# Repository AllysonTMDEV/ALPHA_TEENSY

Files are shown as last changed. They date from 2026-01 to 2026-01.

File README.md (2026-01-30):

# AFC - Alpha Flight Controller (Teensy 4.1)





## Visao Geral

Controlador de navegacao desenvolvido pela **Alpha Subsea** para ROVs e drones subaquaticos, baseado na plataforma **Teensy 4.1** (ARM Cortex-M7 @ 600MHz).

### Caracteristicas Principais:
- **MCU:** Teensy 4.1 (600MHz, 1MB RAM)
- **Sensores:** IMU (ICM-42688-P), Magnetometro (LIS3MDL), Barometro (BMP390), Profundidade (MS5837-30BA)
- **PWM:** 16 canais via PCA9685 (8 thrusters + 4 servos)
- **Comunicacao:** Serial 1Mbps com Raspberry Pi
- **ADC:** ADS1115 16-bit para monitoramento de tensao/corrente

## Estrutura de Arquivos

```
AFC_CICLO DESENVOLVIMENTO.html    # Ciclo de desenvolvimento (40% completo)
AFC_TEENSY_PCB_DOCUMENTACAO.md    # Documentacao tecnica completa
BOM_AFC_TEENSY_LCSC.csv           # Lista de materiais com codigos LCSC
Gerber_*.zip                       # Arquivos Gerber para fabricacao
PCB_*.json                         # PCB EasyEDA
PCB_*.kicad_pcb                    # PCB KiCad
SCH_*.json                         # Esquematico EasyEDA
Schematic_*.pdf                    # Esquematico PDF
Sheet_1_*.schdoc                   # Esquematico Altium (para KiCad)
*.png                              # Screenshots de validacao
```

## Status do Projeto

| Fase | Progresso | Status |
|---|---|---|
| 1. Plan | 100% | Concluido |
| 2. Code | 100% | Firmware + Esquematico prontos |
| 3. Build | 100% | Gerbers prontos para fabricacao |
| 4. Test | 0% | Pendente |
| 5. Homologation | 0% | Pendente |

**Progresso Geral: 42%**

## BOM - Lista de Materiais

Total de **63 componentes** com codigos LCSC para montagem SMD.

### Componentes Principais:
| Componente | Modelo | LCSC |
|---|---|---|
| IMU 6-DoF | ICM-42688-P | C1850418 |
| Magnetometro | LIS3MDL | C478483 |
| Barometro | BMP390 | C9900016584 |
| PWM Driver | PCA9685PW | C2678753 |
| ADC 16-bit | ADS1115 | C37593 |
| Buck Converter | MP1584EN | C15051 |
| Power Monitor | INA226 | C49851 |

**Custo estimado:** ~$50-70 USD (sem Teensy e MS5837)

## Como Fabricar

1. **Fabricacao da PCB:**
   - Utilizar o arquivo `Gerber_*.zip` para fabricacao
   - BOM disponivel em `BOM_AFC_TEENSY_LCSC.csv`

2. **Importar no KiCad 9.0:**
   - `File` -> `Import Project...` -> `Altium Designer`
   - Selecionar `Sheet_1_*.schdoc`

## Firmware

Firmware desenvolvido em PlatformIO com as seguintes features:
- Loop de controle a 400Hz
- PID com anti-windup
- Mixer para 8 thrusters (BlueROV2 Heavy)
- Protocolo binario com CRC16
- Telemetria a 50Hz

## Documentacao

- [Documentacao Tecnica](AFC_TEENSY_PCB_DOCUMENTACAO.md)
- [Ciclo de Desenvolvimento](AFC_CICLO%20DESENVOLVIMENTO.html)
- [BOM LCSC](BOM_AFC_TEENSY_LCSC.csv)

## Equipe

**Alpha Subsea** - Tecnologia Submarina  
Desenvolvido por **Arbor Gestao**

---

*Ultima atualizacao: Janeiro 2026*

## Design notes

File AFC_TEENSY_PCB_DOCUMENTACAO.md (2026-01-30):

# DOCUMENTACAO TECNICA - AFC TEENSY PCB
## Placa de Controle para ROV (Remotely Operated Vehicle)

---

## 1. INFORMACOES GERAIS DO PROJETO

| Parametro | Valor |
|---|---|
| Nome do Projeto | AFC Teensy Controller |
| Versao | 1.0 |
| Data de Criacao | Janeiro 2026 |
| Plataforma de Design | EasyEDA |
| Fabricante Alvo | JLCPCB |

---

## 2. ESPECIFICACOES DA PCB

| Parametro | Valor |
|---|---|
| Dimensoes | 100mm x 80mm |
| Camadas de Cobre | 2 (Top e Bottom) |
| Formato | Retangular |
| Unidade de Medida | Milimetros (mm) |
| Espessura da Placa | 1.6mm (padrao) |
| Material | FR-4 |

---

## 3. LISTA COMPLETA DE COMPONENTES E FOOTPRINTS

### 3.1 Microcontrolador

| Designador | Componente | Descricao | Footprint |
|---|---|---|---|
| U1 | Teensy 4.1 | Microcontrolador principal ARM Cortex-M7 | Modulo Teensy 4.1 |

### 3.2 Sensores I2C

| Designador | Componente | Descricao | Footprint | Endereco I2C |
|---|---|---|---|---|
| U2 | INA226 | Monitor de corrente/tensao | MSOP-10 | 0x40 |
| U3 | ICM-42688-P | IMU 6-DOF (Acelerometro + Giroscopio) | QFN-14 | 0x68 |
| U4 | LIS3MDL | Magnetometro 3 eixos | LGA-12 | 0x1C |
| U5 | BMP390 | Barometro/Altimetro | LGA-10 | 0x76 |
| U6 | ADS1115 | ADC 16-bit 4 canais | MSOP-10 | 0x48 |

### 3.3 Reguladores de Tensao

| Designador | Componente | Descricao | Entrada | Saida | Footprint |
|---|---|---|---|---|---|
| U7 | MP1584EN | Regulador DC-DC Step-Down | 12V | 5V | SOIC-8 |
| U8 | AMS1117-3.3 | Regulador LDO | 5V | 3.3V | SOT-223 |
| U12 | MP1584EN | Regulador DC-DC Step-Down (secundario) | 12V | 5V | SOIC-8 |

### 3.4 Circuitos de Protecao e Monitoramento

| Designador | Componente | Descricao | Footprint |
|---|---|---|---|
| U10 | Voltage Monitor | Monitor de tensao | SOT-23 |
| U11 | Crystal 32.768kHz | Cristal oscilador | HC-49S |
| D1 | SMBJ24A-TR | TVS Diode protecao ESD | SMB |
| D2 | SS34 | Diodo Schottky | SMA |
| D3 | SS34 | Diodo Schottky | SMA |

### 3.5 Conectores de Servo/PWM (3 pinos) - ATUALIZADOS

| Designador | Funcao | Footprint Original | Footprint Atualizado | LCSC Code |
|---|---|---|---|---|
| U13 (RX/TX11) | Servo Output 11 | SM03B-GHS-TB | CONN-TH_3P-P2.50_B3B-XH-A-BK-LF-SN | C144394 |
| U14 (RX/TX10) | Servo Output 10 | SM03B-GHS-TB | CONN-TH_3P-P2.50_B3B-XH-A-BK-LF-SN | C144394 |
| U15 (RX/TX9) | Servo Output 9 | SM03B-GHS-TB | CONN-TH_3P-P2.50_B3B-XH-A-BK-LF-SN | C144394 |
| U16 (RX/TX8) | Servo Output 8 | SM03B-GHS-TB | CONN-TH_3P-P2.50_B3B-XH-A-BK-LF-SN | C144394 |
| U17 (RX/TX7) | Servo Output 7 | SM03B-GHS-TB | CONN-TH_3P-P2.50_B3B-XH-A-BK-LF-SN | C144394 |
| U18 (RX/TX6) | Servo Output 6 | SM03B-GHS-TB | CONN-TH_3P-P2.50_B3B-XH-A-BK-LF-SN | C144394 |
| U19 (RX/TX5) | Servo Output 5 | SM03B-GHS-TB | CONN-TH_3P-P2.50_B3B-XH-A-BK-LF-SN | C144394 |
| U20 (RX/TX4) | Servo Output 4 | SM03B-GHS-TB | CONN-TH_3P-P2.50_B3B-XH-A-BK-LF-SN | C144394 |
| U21 (RX/TX3) | Servo Output 3 | SM03B-GHS-TB | CONN-TH_3P-P2.50_B3B-XH-A-BK-LF-SN | C144394 |
| U22 (RX/TX2) | Servo Output 2 | SM03B-GHS-TB | CONN-TH_3P-P2.50_B3B-XH-A-BK-LF-SN | C144394 |
| U23 (RX/TX1) | Servo Output 1 | SM03B-GHS-TB | CONN-TH_3P-P2.50_B3B-XH-A-BK-LF-SN | C144394 |

Pinagem dos conectores de servo (B3B-XH-A):
- Pino 1: GND
- Pino 2: VCC (5V)
- Pino 3: Sinal PWM

### 3.6 Conectores I2C (4 pinos) - ATUALIZADOS

| Designador | Funcao | Footprint Original | Footprint Atualizado | LCSC Code |
|---|---|---|---|---|
| P1 | I2C Port 1 | JST-4PIN | CONN-TH_B4B-XH-A-LF-SN | C144395 |
| P2 | I2C Port 2 | JST-4PIN | CONN-TH_B4B-XH-A-LF-SN | C144395 |
| P3 | I2C Port 3 | JST-4PIN | CONN-TH_B4B-XH-A-LF-SN | C144395 |
| P4 | I2C Port 4 | JST-4PIN | CONN-TH_B4B-XH-A-LF-SN | C144395 |
| P5 | I2C Port 5 | JST-4PIN | CONN-TH_B4B-XH-A-LF-SN | C144395 |
| P6 | I2C Port 6 | JST-4PIN | CONN-TH_B4B-XH-A-LF-SN | C144395 |
| P7 | I2C Port 7 | JST-4PIN | CONN-TH_B4B-XH-A-LF-SN | C144395 |
| P8 | I2C Port 8 | JST-4PIN | CONN-TH_B4B-XH-A-LF-SN | C144395 |

Pinagem dos conectores I2C (B4B-XH-A):
- Pino 1: GND
- Pino 2: VCC (3.3V)
- Pino 3: SDA
- Pino 4: SCL

### 3.7 Outros Conectores

| Designador | Componente | Descricao | Footprint |
|---|---|---|---|
| CN1 | Conector de Entrada | Entrada de alimentacao principal 12V | Conector Screw Terminal |
| P9 | Header 2x5 | Conector de expansao | PHD2.0mm-2X5 |

### 3.8 Componentes de Interface

| Designador | Componente | Descricao | Footprint |
|---|---|---|---|
| SW1 | Tactile Switch | Botao ARM | 6x6mm Tactile |
| SW2 | Tactile Switch | Botao Emergency Stop | 6x6mm Tactile |
| LED1 | WS2812B-5050 | LED RGB Status 1 | LED-SMD_5050 |
| LED2 | WS2812B-5050 | LED RGB Status 2 | LED-SMD_5050 |
| BUZZER1 | Buzzer 2700Hz | Buzzer piezoeletrico | BUZ-SMD_4P-L8.5 |

### 3.9 Transistores/MOSFETs

| Designador | Componente | Descricao | Footprint |
|---|---|---|---|
| Q1 | AO3400A | N-Channel MOSFET | SOT-23-3 |
| Q2 | AO3400A | N-Channel MOSFET | SOT-23-3 |

### 3.10 Resistores

| Designador | Valor | Descricao | Footprint |
|---|---|---|---|
| R1 | 10K | Pull-up/Pull-down | 0402 |
| R2 | 10K | Pull-up/Pull-down | 0402 |
| R3 | 10K | Pull-up/Pull-down | 0402 |
| R4 | 10K | Pull-up/Pull-down | 0402 |
| R5 | 10K | Pull-up/Pull-down | 0402 |
| R6 | 10K | Pull-up/Pull-down | 0402 |
| R7 | 10K | Pull-up/Pull-down | 0402 |
| R8 | 10K | Pull-up/Pull-down | 0402 |
| R9 | 4.7K | Pull-up I2C SDA | 0402 |
| R10 | 4.7K | Pull-up I2C SCL | 0402 |
| R11 | 1K | Resistor LED | 0402 |
| R12 | 1K | Resistor LED | 0402 |
| R13 | 100R | Resistor de protecao | 0402 |
| R14 | 100R | Resistor de protecao | 0402 |
| R15 | 100R | Resistor de protecao | 0402 |
| R16 | 100R | Resistor de protecao | 0402 |
| R17 | 0.1R | Resistor shunt para INA226 | 2512 |

### 3.11 Capacitores

| Designador | Valor | Descricao | Footprint |
|---|---|---|---|
| C1 | 10uF | Capacitor de desacoplamento | 0805 |
| C2 | 10uF | Capacitor de desacoplamento | 0805 |
| C3 | 10uF | Capacitor de desacoplamento | 0805 |
| C4 | 10uF | Capacitor de desacoplamento | 0805 |
| C5 | 100nF | Capacitor de bypass | 0402 |
| C6 | 100nF | Capacitor de bypass | 0402 |
| C7 | 100nF | Capacitor de bypass | 0402 |
| C8 | 100nF | Capacitor de bypass | 0402 |
| C9 | 100nF | Capacitor de bypass | 0402 |
| C10 | 100nF | Capacitor de bypass | 0402 |
| C11 | 100nF | Capacitor de bypass | 0402 |
| C12 | 100nF | Capacitor de bypass | 0402 |
| C13 | 100nF | Capacitor de bypass | 0402 |
| C14 | 100nF | Capacitor de bypass | 0402 |
| C15 | 100nF | Capacitor de bypass | 0402 |
| C16 | 1uF | Capacitor de filtragem | 0402 |
| C17 | 22uF | Capacitor regulador entrada | 0805 |
| C18 | 22uF | Capacitor regulador saida | 0805 |
| C19 | 47uF | Capacitor bulk entrada | 1206 |
| C20 | 47uF | Capacitor bulk saida | 1206 |

---

## 4. HISTORICO DE ALTERACOES

### 4.1 Alteracoes de Footprint

| Data | Componentes | Alteracao | Motivo |
|---|---|---|---|
| Jan 2026 | U13-U23 (RX/TX1-11) | SM03B-GHS-TB para B3B-XH-A | Orientacao vertical para facilitar conexao de cabos pela parte superior |
| Jan 2026 | P1-P8 | JST-4PIN generico para B4B-XH-A | Footprint com modelo 3D e compativel com JLCPCB |

### 4.2 Alteracoes de Nomenclatura

| Componente Original | Novo Nome | Motivo |
|---|---|---|
| RX/TX1 | U23 | Padronizacao de nomenclatura |
| RX/TX2 | U22 | Padronizacao de nomenclatura |
| RX/TX3 | U21 | Padronizacao de nomenclatura |
| RX/TX4 | U20 | Padronizacao de nomenclatura |
| RX/TX5 | U19 | Padronizacao de nomenclatura |
| RX/TX6 | U18 | Padronizacao de nomenclatura |
| RX/TX7 | U17 | Padronizacao de nomenclatura |
| RX/TX8 | U16 | Padronizacao de nomenclatura |
| RX/TX9 | U15 | Padronizacao de nomenclatura |
| RX/TX10 | U14 | Padronizacao de nomenclatura |
| RX/TX11 | U13 | Padronizacao de nomenclatura |

---

## 5. LAYOUT DA PCB

### 5.1 Distribuicao de Areas

| Area | Localizacao | Componentes |
|---|---|---|
| Entrada de Energia | Borda esquerda superior | CN1, D1, U10 |
| Reguladores | Topo central-esquerdo | U7, U8, U12, C17-C20 |
| Microcontrolador | Centro-esquerda | U1 (Teensy) |
| Sensores I2C | Centro-esquerda | U2, U3, U4, U5, U6, U11 |
| Interface Usuario | Topo central | SW1, SW2, LED1, LED2, BUZZER1 |
| Conectores PWM | Centro | RX/TX1-11 (U13-U23) em grade 4x3 |
| Conectores I2C | Inferior central | P1-P8 em grade 4x2 |
| Conector Expansao | Borda direita | P9 |
| MOSFETs | Direita superior | Q1, Q2 |
| Resistores | Borda direita | R1-R17 |
| Capacitores | Borda inferior | C1-C16 |

### 5.2 Furos de Montagem

| Posicao | Coordenadas Aproximadas |
|---|---|
| Canto superior esquerdo | (5mm, 5mm) |
| Canto superior direito | (95mm, 5mm) |
| Canto inferior esquerdo | (5mm, 75mm) |
| Canto inferior direito | (95mm, 75mm) |

---

## 6. REDES DE ALIMENTACAO

### 6.1 Tensoes do Sistema

| Rede | Tensao | Fonte | Consumidores |
|---|---|---|---|
| VIN | 12V | Entrada externa | Reguladores |
| 5V | 5V | U7 (MP1584EN) | Servos, Teensy |
| 3V3 | 3.3V | U8 (AMS1117) | Sensores I2C, LEDs |
| GND | 0V | Referencia comum | Todos os componentes |

### 6.2 Barramentos

| Barramento | Sinais | Componentes Conectados |
|---|---|---|
| I2C | SDA, SCL | U2, U3, U4, U5, U6, P1-P8 |
| PWM | PWM1-PWM11 | U13-U23 |
| SPI | MOSI, MISO, SCK, CS | Reservado |

---

## 7. CONSIDERACOES DE DESIGN

### 7.1 Orientacao dos Conectores

Todos os conectores de servo (U13-U23) e I2C (P1-P8) foram posicionados com a abertura voltada para CIMA, permitindo:
- Conexao de cabos pela parte superior da placa
- Facilidade de manutencao
- Acesso visual aos conectores durante operacao

### 7.2 Posicionamento de Componentes Criticos

- Capacitores de desacoplamento proximos aos pinos de alimentacao dos ICs
- Resistor shunt (R17) proximo ao INA226 (U2)
- Cristal (U11) proximo ao microcontrolador
- Reguladores afastados dos sensores para minimizar interferencia termica

### 7.3 Recomendacoes para Roteamento

- Trilhas de alimentacao: minimo 0.5mm de largura
- Trilhas de sinal: 0.25mm de largura
- Via termica sob reguladores
- Plano de terra continuo na camada inferior
- Evitar trilhas longas para sinais I2C

---

## 8. LISTA DE MATERIAIS (BOM) - CODIGOS LCSC ATUALIZADOS

### 8.1 ICs Principais

| Ref | LCSC | Componente | Footprint | Tipo |
|-----|---|---|---|---|
| U1 | C2678753 | PCA9685PW,118 (PWM Driver 16ch) | TSSOP-28 | Extended |
| U2 | C37593 | ADS1115IDGSR (ADC 16-bit) | MSOP-10 | Extended |
| U3 | C1850418 | ICM-42688-P (IMU 6-axis) | LGA-14 | Extended |
| U4 | C478483 | LIS3MDLTR (Magnetometro) | LGA-12 | Extended |
| U5 | C9900016584 | BMP390 (Barometro) | LGA-10 | Extended |
| U6 | C49851 | INA226AIDGSR (Power Monitor) | MSOP-10 | Extended |
| U7 | C15051 | MP1584EN-LF-Z (Buck 3A) | SOIC-8 EP | Extended |
| U8 | C6186 | AMS1117-3.3 (LDO 3.3V) | SOT-223 | Basic |
| U10 | C9900007450 | PPTC 1.5A/13.2V (Fusivel) | 1206 | Extended |
| U11 | C17701336 | Crystal 24MHz | SMD 3225 | Extended |

### 8.2 Diodos e Transistores

| Ref | LCSC | Componente | Footprint | Tipo |
|-----|---|---|---|---|
| D1 | C133668 | SMBJ24A-TR (TVS 24V) | SMB | Extended |
| D2 | C8678 | SS34 (Schottky 3A 40V) | SMA | Basic |
| D3 | C8678 | SS34 (Schottky 3A 40V) | SMA | Basic |
| Q1 | C20917 | AO3400A (MOSFET N-CH) | SOT-23 | Basic |
| Q2 | C20917 | AO3400A (MOSFET N-CH) | SOT-23 | Basic |

### 8.3 Resistores

| Ref | LCSC | Valor | Footprint | Tipo |
|-----|---|---|---|---|
| R1-R8 | C25744 | 10kΩ | 0402 | Basic |
| R9-R12 | C25900 | 4.7kΩ | 0402 | Basic |
| R13-R16 | C2889360 | 330Ω | 0402 | Extended |
| R17 | C76272 | 0.01Ω 1W Shunt | 2512 | Extended |

### 8.4 Capacitores

| Ref | LCSC | Valor | Footprint | Tipo |
|-----|---|---|---|---|
| C1-C4 | C15850 | 10uF 25V | 0805 | Basic |
| C5-C12 | C1525 | 100nF 50V | 0402 | Basic |
| C13-C16 | C52923 | 1uF 16V | 0402 | Basic |
| C17-C18 | C45783 | 22uF 25V | 0805 | Basic |
| C19-C20 | C5448950 | 47uF 10V | 1206 | Extended |

### 8.5 LEDs, Buzzer e Conectores

| Ref | LCSC | Componente | Footprint | Tipo |
|-----|---|---|---|---|
| LED1-LED2 | C2838584 | WS2812B-5050RGB | 5050 | Extended |
| BUZZER1 | C94599 | MLT-8530 (2700Hz) | SMD 8.5x8.5 | Extended |
| CN1 | C5306499 | S4B-XH-SM4-TB(LF)(SN) | JST XH 4P | Extended |
| P9 | C49123 | PHD2.0mm-2X5 Header | THT 2x5 | Extended |

### 8.6 Resumo de Quantidades

| Categoria | Quantidade |
|---|---|
| ICs | 11 |
| Diodos | 3 |
| Transistores | 2 |
| Resistores | 17 |
| Capacitores | 20 |
| LEDs | 2 |
| Buzzer | 1 |
| Conectores | 2 |
| **TOTAL SMT** | **58** |
| Teensy 4.1 (separado) | 1 |

### 8.7 Estimativa de Custos (USD)

| Item | Valor |
|---|---|
| Basic Parts (35 unid) | ~$1.50 |
| Extended Parts (28 unid) | ~$25-30 |
| Taxa Extended (17 tipos x $3) | ~$51 |
| PCB (5 unidades) | ~$5-10 |
| Teensy 4.1 | ~$30 |
| **TOTAL** | **~$115-125** |

---

## 9. PROXIMOS PASSOS

| Etapa | Status | Descricao |
|---|---|---|
| 1. Esquematico | COMPLETO | Diagrama multifilar finalizado |
| 2. Conversao para PCB | COMPLETO | Importacao de componentes |
| 3. Atualizacao de Footprints | COMPLETO | U13-U23 e P1-P8 atualizados |
| 4. Posicionamento | COMPLETO | Layout conforme guia visual |
| 5. Auto-Router | COMPLETO | Roteamento das trilhas |
| 6. Planos de Cobre | COMPLETO | GND e VCC planes |
| 7. DRC | COMPLETO | 0 erros |
| 8. Gerber | COMPLETO | Arquivos gerados |
| 9. BOM LCSC | COMPLETO | Lista atualizada com codigos |

---

## 10. ARQUIVOS DO PROJETO

| Arquivo | Descricao |
|---|---|
| SCH_PROJETO-AFC-(LAYOUT-ATUALIZADO-002)_2026-01-30.json | Esquematico EasyEDA |
| Schematic_PROJETO-AFC-(LAYOUT-ATUALIZADO-002)_2026-01-30.pdf | Esquematico PDF |
| PCB_PCB_PROJETO-AFC-(LAYOUT-ATUALIZADO-002)_2_2026-01-30.json | PCB EasyEDA |
| PCB_PCB_PROJETO-AFC-(LAYOUT-ATUALIZADO-002)_2_2026-01-30.kicad_pcb | PCB KiCad |
| PCB_PCB_PROJETO-AFC-(LAYOUT-ATUALIZADO-002)_2_2026-01-30.pdf | PCB PDF |
| Gerber_PROJETO-AFC-...2026-01-30.zip | Arquivos Gerber para JLCPCB |
| BOM_AFC_TEENSY_LCSC.csv | Lista de materiais com codigos LCSC |
| AFC_TEENSY_PCB_DOCUMENTACAO.md | Esta documentacao |
| PLACA AFC FINAL 0 ERROS.png | Screenshot DRC aprovado |

---

## 11. INFORMACOES DE CONTATO E REVISAO

| Campo | Valor |
|---|---|
| Projetista | [Nome do Projetista] |
| Revisao | 1.0 |
| Data da Documentacao | Janeiro 2026 |
| Ultima Atualizacao | 30/01/2026 |

---

## NOTAS ADICIONAIS

1. Os footprints B3B-XH-A e B4B-XH-A sao conectores JST XH series, amplamente disponiveis e compativeis com JLCPCB SMT assembly.

2. Os conectores foram especificamente escolhidos para ter orientacao vertical, facilitando a conexao de cabos externos.

3. O layout foi inspirado na placa Navigator da BlueRobotics, otimizado para aplicacoes de ROV.

4. Todos os componentes possuem codigos LCSC validos para fabricacao via JLCPCB.

---

FIM DO DOCUMENTO

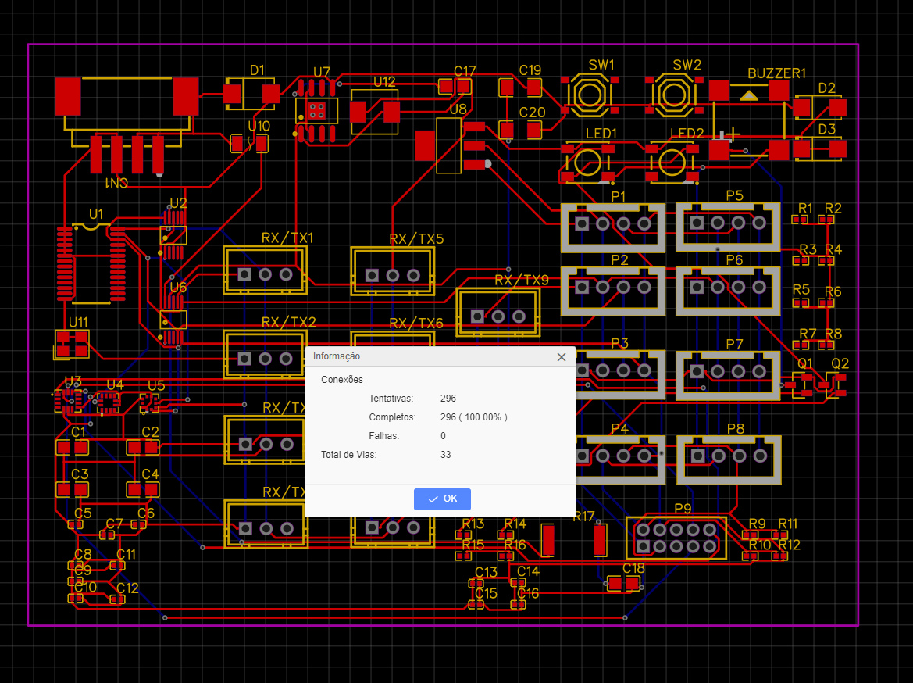
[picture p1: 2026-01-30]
PLACA AFC FINAL 0 ERROS.png

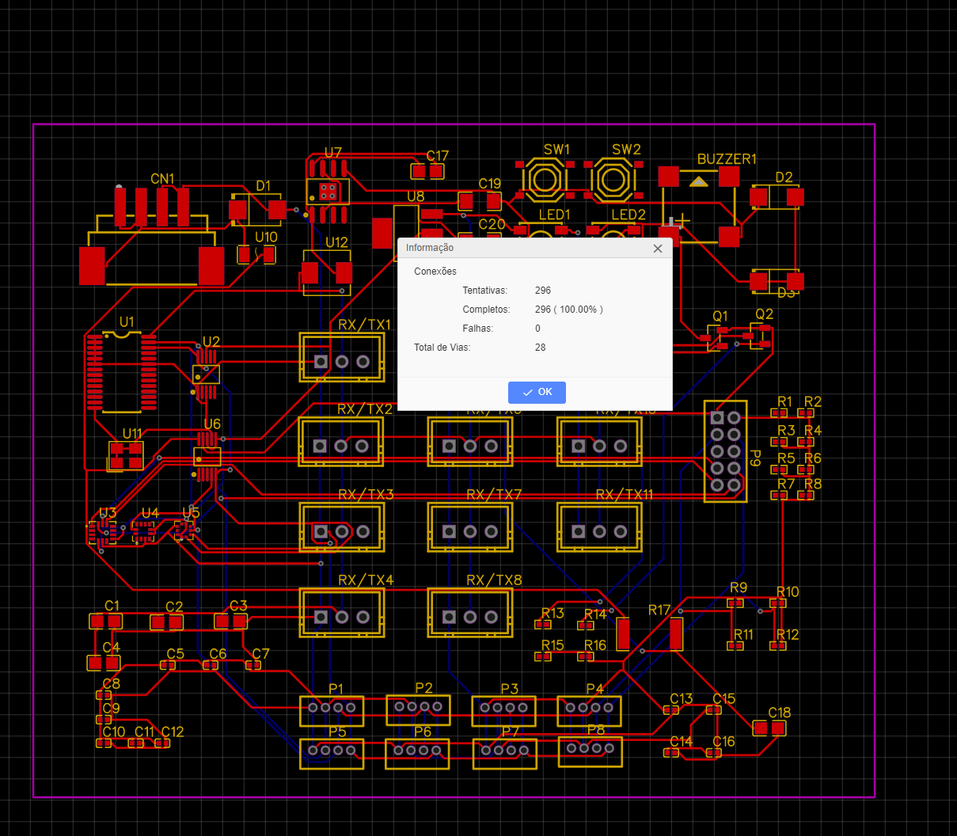
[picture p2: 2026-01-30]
RETRABALHO FOOTPRINT ZERO ERROS TEENSY.png

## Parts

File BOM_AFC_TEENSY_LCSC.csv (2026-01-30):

Referencia | Quantidade | Valor/Part Number | Descricao | Footprint | LCSC | Tipo JLCPCB
========== ICs PRINCIPAIS ==========
U1 | 1 | PCA9685PW 118 | PWM Driver 16ch I2C | TSSOP-28 | C2678753 | Extended Part
U2 | 1 | ADS1115IDGSR | ADC 16-bit 4ch I2C | MSOP-10 | C37593 | Extended Part
U3 | 1 | ICM-42688-P | IMU 6-axis Accel/Gyro | LGA-14 | C1850418 | Extended Part
U4 | 1 | LIS3MDLTR | Magnetometro 3-axis I2C | LGA-12 | C478483 | Extended Part
U5 | 1 | BMP390 | Barometro/Altimetro I2C | LGA-10 | C9900016584 | Extended Part
U6 | 1 | INA226AIDGSR | Monitor Corrente/Tensao I2C | MSOP-10 | C49851 | Extended Part
U7 | 1 | MP1584EN-LF-Z | Buck Converter 3A | SOIC-8 EP | C15051 | Extended Part
U8 | 1 | AMS1117-3.3 | LDO Regulador 3.3V 1A | SOT-223 | C6186 | Basic Part
U10 | 1 | PPTC 1.5A/13.2V | Fusivel Resetavel | 1206 | C9900007450 | Extended Part
U11 | 1 | 7325-2400A1210-03 | Crystal 24MHz | SMD 3225 | C17701336 | Extended Part
========== DIODOS ==========
D1 | 1 | SMBJ24A-TR | TVS Diodo 24V | SMB | C133668 | Extended Part
D2 | 1 | SS34 | Schottky Diodo 3A 40V | SMA | C8678 | Basic Part
D3 | 1 | SS34 | Schottky Diodo 3A 40V | SMA | C8678 | Basic Part
========== TRANSISTORES ==========
Q1 | 1 | AO3400A | MOSFET N-CH 30V 5.7A | SOT-23 | C20917 | Basic Part
Q2 | 1 | AO3400A | MOSFET N-CH 30V 5.7A | SOT-23 | C20917 | Basic Part
========== RESISTORES ==========
R1 | 1 | 10kΩ | Resistor SMD | 0402 | C25744 | Basic Part
R2 | 1 | 10kΩ | Resistor SMD | 0402 | C25744 | Basic Part
R3 | 1 | 10kΩ | Resistor SMD | 0402 | C25744 | Basic Part
R4 | 1 | 10kΩ | Resistor SMD | 0402 | C25744 | Basic Part
R5 | 1 | 10kΩ | Resistor SMD | 0402 | C25744 | Basic Part
R6 | 1 | 10kΩ | Resistor SMD | 0402 | C25744 | Basic Part
R7 | 1 | 10kΩ | Resistor SMD | 0402 | C25744 | Basic Part
R8 | 1 | 10kΩ | Resistor SMD | 0402 | C25744 | Basic Part
R9 | 1 | 4.7kΩ | Resistor SMD | 0402 | C25900 | Basic Part
R10 | 1 | 4.7kΩ | Resistor SMD | 0402 | C25900 | Basic Part
R11 | 1 | 4.7kΩ | Resistor SMD | 0402 | C25900 | Basic Part
R12 | 1 | 4.7kΩ | Resistor SMD | 0402 | C25900 | Basic Part
R13 | 1 | 330Ω | Resistor SMD | 0402 | C2889360 | Extended Part
R14 | 1 | 330Ω | Resistor SMD | 0402 | C2889360 | Extended Part
R15 | 1 | 330Ω | Resistor SMD | 0402 | C2889360 | Extended Part
R16 | 1 | 330Ω | Resistor SMD | 0402 | C2889360 | Extended Part
R17 | 1 | 0.01Ω 1W | Resistor Shunt Sense | 2512 | C76272 | Extended Part
========== CAPACITORES ==========
C1 | 1 | 10uF 25V | Capacitor Ceramico | 0805 | C15850 | Basic Part
C2 | 1 | 10uF 25V | Capacitor Ceramico | 0805 | C15850 | Basic Part
C3 | 1 | 10uF 25V | Capacitor Ceramico | 0805 | C15850 | Basic Part
C4 | 1 | 10uF 25V | Capacitor Ceramico | 0805 | C15850 | Basic Part
C5 | 1 | 100nF 50V | Capacitor Ceramico | 0402 | C1525 | Basic Part
C6 | 1 | 100nF 50V | Capacitor Ceramico | 0402 | C1525 | Basic Part
C7 | 1 | 100nF 50V | Capacitor Ceramico | 0402 | C1525 | Basic Part
C8 | 1 | 100nF 50V | Capacitor Ceramico | 0402 | C1525 | Basic Part
C9 | 1 | 100nF 50V | Capacitor Ceramico | 0402 | C1525 | Basic Part
C10 | 1 | 100nF 50V | Capacitor Ceramico | 0402 | C1525 | Basic Part
C11 | 1 | 100nF 50V | Capacitor Ceramico | 0402 | C1525 | Basic Part
C12 | 1 | 100nF 50V | Capacitor Ceramico | 0402 | C1525 | Basic Part
C13 | 1 | 1uF 16V | Capacitor Ceramico | 0402 | C52923 | Basic Part
C14 | 1 | 1uF 16V | Capacitor Ceramico | 0402 | C52923 | Basic Part
C15 | 1 | 1uF 16V | Capacitor Ceramico | 0402 | C52923 | Basic Part
C16 | 1 | 1uF 16V | Capacitor Ceramico | 0402 | C52923 | Basic Part
C17 | 1 | 22uF 25V | Capacitor Ceramico | 0805 | C45783 | Basic Part
C18 | 1 | 22uF 25V | Capacitor Ceramico | 0805 | C45783 | Basic Part
C19 | 1 | 47uF 10V | Capacitor Ceramico | 1206 | C5448950 | Extended Part
C20 | 1 | 47uF 10V | Capacitor Ceramico | 1206 | C5448950 | Extended Part
========== LEDs e BUZZER ==========
LED1 | 1 | WS2812B-5050RGB | LED RGB Enderecavel | 5050 | C2838584 | Extended Part
LED2 | 1 | WS2812B-5050RGB | LED RGB Enderecavel | 5050 | C2838584 | Extended Part
BUZZER1 | 1 | MLT-8530 | Buzzer 2700Hz | SMD 8.5x8.5 | C94599 | Extended Part
========== CONECTORES ==========
CN1 | 1 | S4B-XH-SM4-TB(LF)(SN) | Conector JST XH 4P SMD | XH-4P SMD | C5306499 | Extended Part
P9 | 1 | PHD2.0mm-2X5 | Header 2x5 2mm | THT | C49123 | Extended Part
========================================
RESUMO PARA PEDIDO JLCPCB (ATUALIZADO)
========================================
BASIC PARTS (estoque JLCPCB - sem taxa extra):
LCSC | Qtd | Componente
C6186 | 1 | AMS1117-3.3 LDO
C8678 | 2 | SS34 Schottky
C20917 | 2 | AO3400A MOSFET
C25744 | 8 | 10kΩ 0402
C25900 | 4 | 4.7kΩ 0402
C15850 | 4 | 10uF 0805
C1525 | 8 | 100nF 0402
C52923 | 4 | 1uF 0402
C45783 | 2 | 22uF 0805
EXTENDED PARTS (taxa extra ~$3 por tipo):
LCSC | Qtd | Componente
C2678753 | 1 | PCA9685PW PWM Driver
C37593 | 1 | ADS1115 ADC
C1850418 | 1 | ICM-42688-P IMU
C478483 | 1 | LIS3MDLTR Magnetometro
C9900016584 | 1 | BMP390 Barometro
C49851 | 1 | INA226 Power Monitor
C15051 | 1 | MP1584EN Buck
C9900007450 | 1 | PPTC Fusivel
C17701336 | 1 | Crystal 24MHz
C133668 | 1 | SMBJ24A TVS
C2889360 | 4 | 330Ω 0402
C76272 | 1 | 0.01Ω Shunt
C5448950 | 2 | 47uF 1206
C2838584 | 2 | WS2812B LED RGB
C94599 | 1 | MLT-8530 Buzzer
C5306499 | 1 | JST XH 4P
C49123 | 1 | Header 2x5
========================================
COMPONENTES NAO LCSC (comprar separado)
========================================
TEENSY 4.1 | 1 | Microcontrolador ARM Cortex-M7 600MHz | PJRC Store ou Aliexpress
========================================
TOTAL DE COMPONENTES: 63 unidades
========================================
- ICs: 11
- Diodos: 3
- Transistores: 2
- Resistores: 17
- Capacitores: 20
- LEDs: 2
- Buzzer: 1
- Conectores: 2
- Teensy: 1 (separado)
========================================
ESTIMATIVA DE CUSTOS (USD)
========================================
Basic Parts (35 unid): ~$1.50
Extended Parts (28 unid): ~$25-30
Taxa Extended (17 tipos x $3): ~$51
Teensy 4.1: ~$30
PCB (5 unidades): ~$5-10
TOTAL APROXIMADO: ~$115-125 para 1 placa montada

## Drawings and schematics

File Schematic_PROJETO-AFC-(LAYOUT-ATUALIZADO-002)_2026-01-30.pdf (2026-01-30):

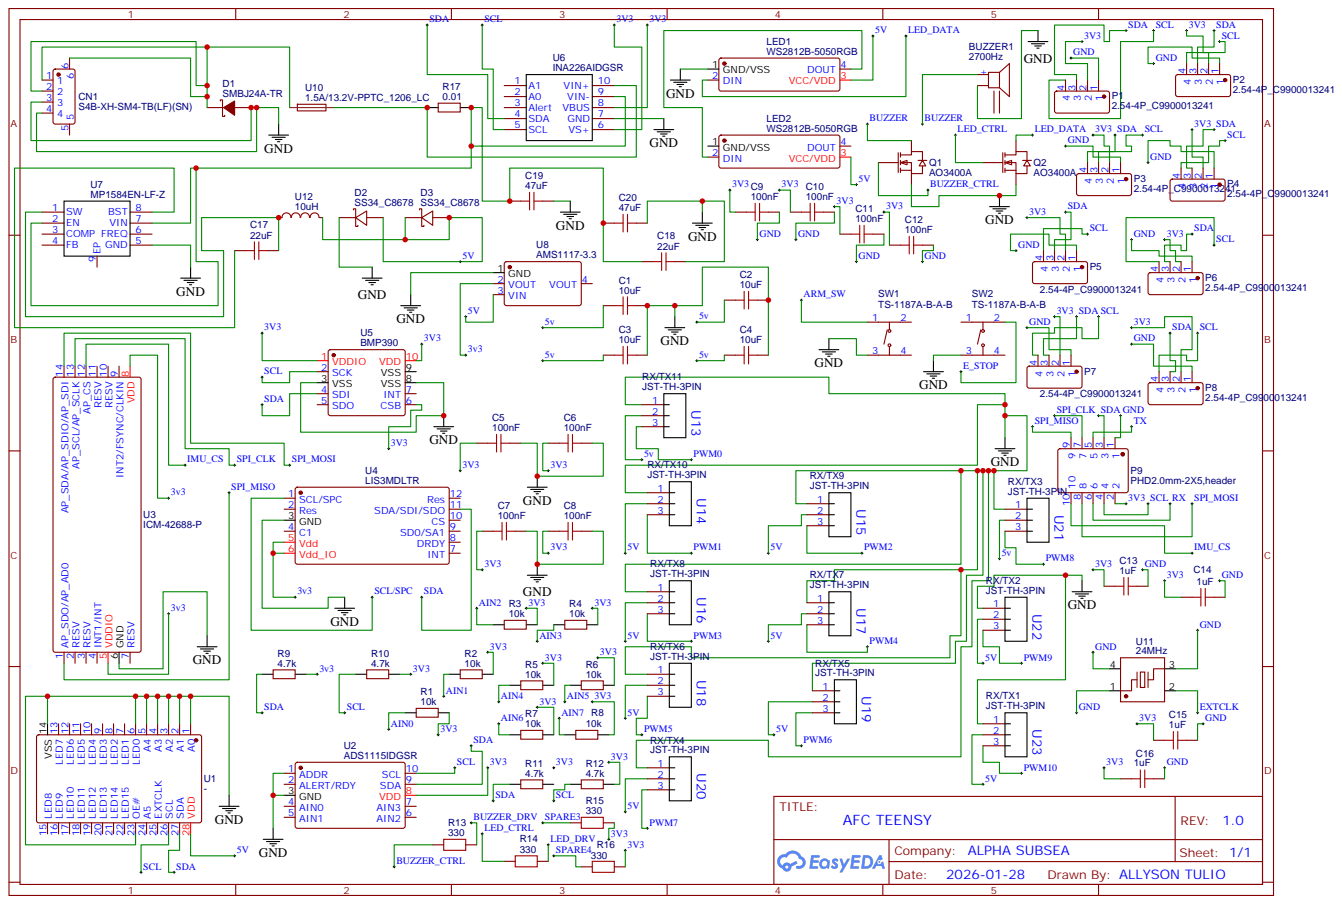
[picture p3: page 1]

Drawn By: ALLYSON TULIO

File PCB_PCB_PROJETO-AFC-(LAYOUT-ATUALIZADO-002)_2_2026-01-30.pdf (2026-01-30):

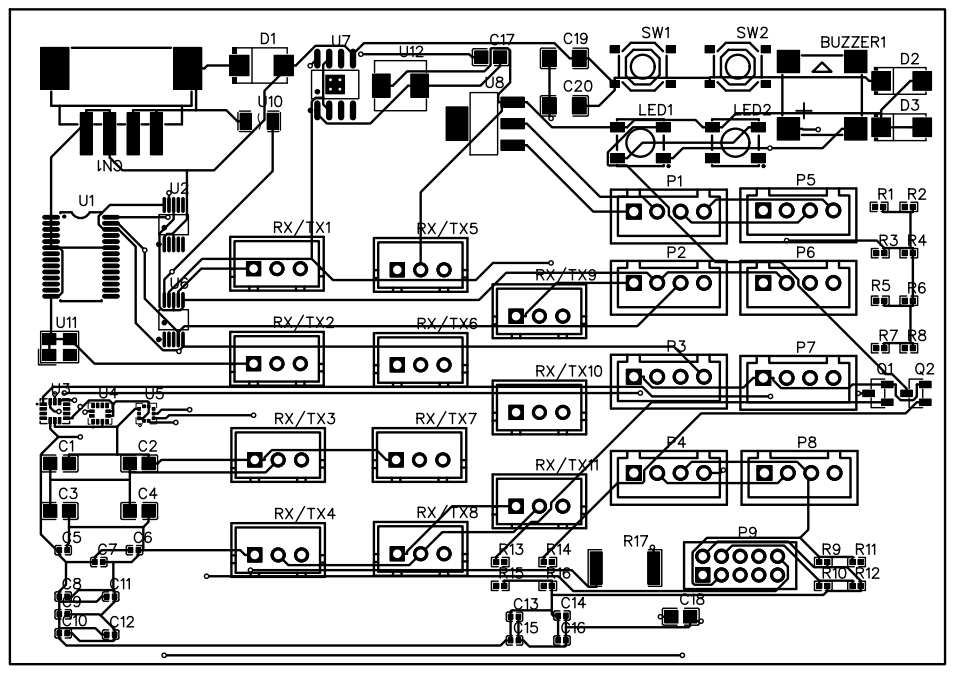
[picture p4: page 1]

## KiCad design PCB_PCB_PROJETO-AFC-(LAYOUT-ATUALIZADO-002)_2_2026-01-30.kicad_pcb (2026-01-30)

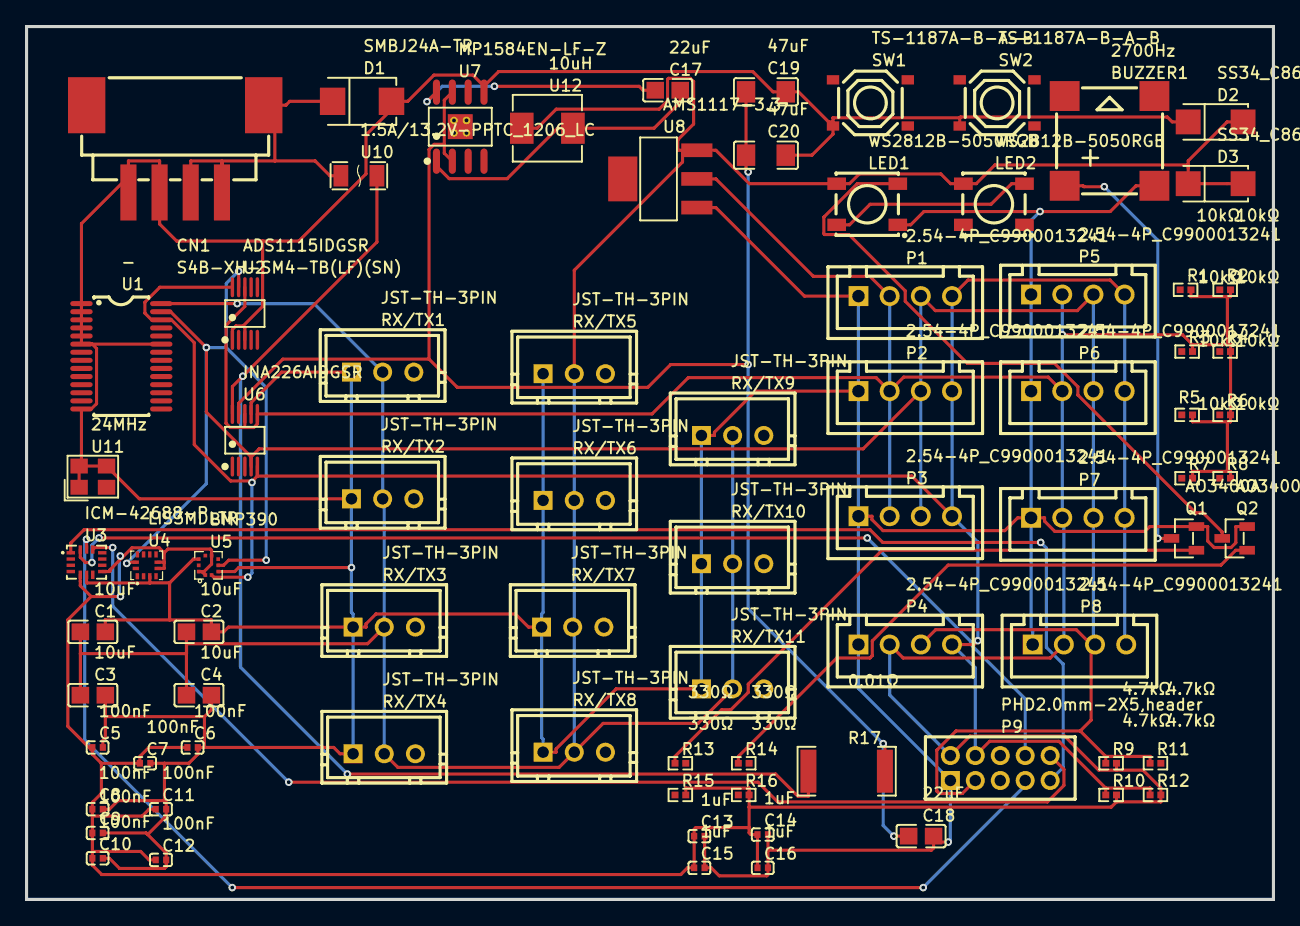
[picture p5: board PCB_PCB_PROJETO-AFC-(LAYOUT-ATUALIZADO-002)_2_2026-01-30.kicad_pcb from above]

Board: 2 copper layers, 100.0 x 70.0 mm, 79 parts (0 on the bottom side), 19 nets.

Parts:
BUZZER1: 2700Hz; BUZ-SMD_4P-L8.5-W8.5-P8.50-BR
C1, C2, C3, C4: 10uF; C0805
C5, C6, C7, C8, C9, C10, C11, C12: 100nF; C0402
C13, C14, C15, C16: 1uF; C0402
C17, C18: 22uF; C0805
C19, C20: 47uF; C1206
CN1: S4B-XH-SM4-TB(LF)(SN); CONN-SMD_S4B-XH-SM4-TB-LF-SN
D1: SMBJ24A-TR; SMB_L4.6-W3.6-LS5.3-RD
D2, D3: SS34_C8678; SMA_L4.3-W2.6-LS5.2-RD
LED1, LED2: WS2812B-5050RGB; LED-SMD_4P-L5.0-W5.0-BR_WS2812B-5050RGB
P1, P2, P3, P4, P5, P6, P7, P8: 2.54-4P_C9900013241; CONN-TH_B4B-XH-A-BK-LF-SN
P9: PHD2.0mm-2X5,header; CONN-TH_10P-P2.00_PHD2.0MM-2X5
Q1, Q2: AO3400A; SOT-23-3_L2.9-W1.3-P1.90-LS2.4-BR
R1, R2, R3, R4, R5, R6, R7, R8: 10kΩ; R0402
R9, R10, R11, R12: 4.7kΩ; R0402
R13, R14, R15, R16: 330Ω; R0402
R17: 0.01Ω; R2512
RX/TX1, RX/TX2, RX/TX3, RX/TX4, RX/TX5, RX/TX6, RX/TX7, RX/TX8, RX/TX9, RX/TX10, RX/TX11: JST-TH-3PIN; CONN-TH_3P-P2.50_B3B-XH-A-BK-LF-SN
SW1, SW2: TS-1187A-B-A-B; SW-SMD_4P-L5.1-W5.1-P3.70-LS6.5-TL_H1.5
U1: -; TSSOP-28_L9.7-W4.4-P0.65-LS6.4-TL
U2: ADS1115IDGSR; MSOP-10_L3.0-W3.0-P0.50-LS5.0-BL
U3: ICM-42688-P; LGA-14_L3.0-W2.5-P0.50-TL
U4: LIS3MDLTR; LGA-12_L2.0-W2.0-P0.50-BL
U5: BMP390; LGA-10_L2.0-W2.0-P0.50-BL
U6: INA226AIDGSR; MSOP-10_L3.0-W3.0-P0.50-LS5.0-BL
U7: MP1584EN-LF-Z; SOIC-8_L5.0-W4.0-P1.27-LS6.0-BL-EP2.0
U8: AMS1117-3.3; SOT-223-3_L6.5-W3.4-P2.30-LS7.0-BR
U10: 1.5A/13.2V-PPTC_1206_LC; F1206
U11: 24MHz; CRYSTAL-SMD_4P-L3.2-W2.5-BL
U12: 10uH; IND-SMD_L5.4-W5.2

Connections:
3V3: C5.1, C6.1, C7.1, C8.1, C9.1, C10.1, C11.1, C12.1, C13.1, C14.1, C15.1, C16.1, P1.2, P2.2, P3.2, P4.2, P5.2, P6.2, P7.2, P8.2, P9.2, R1.2, R2.2, R3.2, R4.2, R5.2, R6.2, R7.2, R8.2, R9.2, R10.2, R12.2, R15.2, R16.2, U2.8, U3.5, U3.8, U4.5, U4.6, U5.1, U5.6, U5.10, U6.6, U6.8, U8.2
5V: C1.1, C2.1, C3.1, C4.1, D2.2, D3.1, D3.2, LED1.3, LED2.3, RX/TX1.2, RX/TX2.2, RX/TX3.2, RX/TX4.2, RX/TX5.2, RX/TX6.2, RX/TX7.2, RX/TX8.2, RX/TX9.2, RX/TX10.2, RX/TX11.2, U1.28, U8.3, U12.2
BUZZER: BUZZER1.1, Q1.3
BUZZER_CTRL: Q1.1, R13.1
CN1_1: CN1.1, CN1.2, CN1.6, D1.1, U10.1
GND: BUZZER1.2, C1.2, C2.2, C3.2, C4.2, C5.2, C6.2, C7.2, C8.2, C9.2, C10.2, C11.2, C12.2, C13.2, C14.2, C15.2, C16.2, C18.2, C19.2, C20.2, CN1.3, CN1.4, D1.2, D2.1, LED1.1, P1.1, P2.1, P3.1, P4.1, P5.1, P6.1, P7.1, P8.1, P9.1, Q1.2, Q2.2, RX/TX1.1, RX/TX2.1, RX/TX3.1, RX/TX4.1, RX/TX5.1, RX/TX6.1, RX/TX7.1, RX/TX8.1, RX/TX9.1, RX/TX10.1, RX/TX11.1, SW1.3, SW2.3, U1.1, U1.2, U1.3, U1.4, U1.5, U1.6, U1.14, U1.23, U2.1, U2.3, U3.6, U4.3, U5.3, U5.8, U6.7, U7.5, U8.1, U11.1, U11.3, U11.4
IMU_CS: P9.10, U3.12
LED1_4: LED1.4, LED2.2
LED_CTRL: Q2.1, R14.1
LED_DATA: LED1.2, Q2.3
R17_2: C18.1, C19.1, C20.1, R17.2, U6.9, U7.2, U7.7
SCL: P1.4, P2.4, P3.4, P4.4, P5.4, P6.4, P7.4, P8.4, P9.4, R10.1, R12.1, U1.26, U2.10, U5.2, U6.5
SDA: P1.3, P2.3, P3.3, P4.3, P5.3, P6.3, P7.3, P8.3, P9.3, R9.1, R11.1, U1.27, U2.9, U4.11, U5.4, U6.4
SPI_CLK: P9.7, U3.13
SPI_MISO: P9.9, U3.1
SPI_MOSI: P9.8, U3.14
U7_1: C17.2, U7.1, U12.1
U7_8: C17.1, U7.8
U10_2: R17.1, U6.10, U10.2

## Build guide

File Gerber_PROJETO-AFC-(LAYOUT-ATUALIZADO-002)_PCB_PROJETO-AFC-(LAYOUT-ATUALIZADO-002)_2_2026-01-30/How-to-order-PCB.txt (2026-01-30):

How to Order PCB

Please refer to:
https://docs.easyeda.com/en/PCB/Order-PCB

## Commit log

2026-01-30 AFC Teensy 4.1 PCB - Versao 1.0 Completa - DRC 0 erros, BOM LCSC 63 componentes, Firmware pronto
    [BOM_AFC_TEENSY_LCSC.csv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]
2026-01-30 correcao de caracteres
